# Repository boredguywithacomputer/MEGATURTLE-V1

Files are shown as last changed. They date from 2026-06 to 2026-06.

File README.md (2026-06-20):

  # MEGATURTLE-V1
An ESP32-S3 based custom drone flight controller that is a part of a bigger project. This is not the entire project, but is the only part that needs funding. 

<a href='https://epicturtle.web.app/demoflightcontroller/'>Here's a link to a demo</a><br>
<a href='https://epicturtle.web.app/schemm.pdf'>PDF version of schematic</a>

It features
- 4 connectors for each individual ESC of my quadcopter
  -  One ESC will supply 5v for the flight controller
- A voltage divider setup that enables measurement of the LiPo battery's voltage and capacity
- An ESP32-S3 Wroom-1 microcontroller
- An IMU consisting of Bosch's BMI270 + BMM150, and an BMP388 Barometer
- Sockets to mount an NRF24L01 module

Note:
DRC says the courtyard two header pins overlap with those of the ESP32's antenna, but I ignored it since I won't need wireless connectivity. 

# Schematic


# Board

<br>



# Bill Of Materials
|Component |Total Price ($)|Part # |Link |Qty|JLCPCB Part #|
|---|---|---|---|---|---|
|22uF |0.472 |CL10A226MQ8NRNC |https://jlcpcb.com/partdetail/60514-CL10A226MQ8NRNC/C59461 |20 |C59461 |
|1uF |0.284 |CL05A105KA5NQNC |https://jlcpcb.com/partdetail/53938-CL05A105KA5NQNC/C52923 |20 |C52923 |
|10uF |0.524 |CL10A106KP8NNNC |https://jlcpcb.com/partdetail/20411-CL10A106KP8NNNC/C19702 |20 |C19702 |
|0.1uF |0.0868 |CL05B104KO5NNNC |https://jlcpcb.com/partdetail/1877-CL05B104KO5NNNC/C1525 |28 |C1525 |
|LED |0.144 |KT-0603R |https://jlcpcb.com/partdetail/Hubei_KENTOElec-KT0603R/C2286 |20 |C2286 |
|BMP388 |4.7298 |BMP388 |https://jlcpcb.com/partdetail/BoschSensortec-BMP388/C779278 |2  |C779278 |
|BMI270 |6.501 |BMI270 |https://jlcpcb.com/partdetail/BoschSensortec-BMI270/C2836813 |2  |C2836813 |
|USB_C_Receptacle_USB2.0_14P|0.3686 |TYPE-C-31-M-12 |https://jlcpcb.com/partdetail/Korean_HropartsElec-TYPE_C_31_M12/C165948  |2  |C165948 |
|Conn_01x03_Pin |7.0924 |TSM-103-01-L-SV |https://jlcpcb.com/partdetail/Samtec-TSM_103_01_LSV/C6886650 |14 |C6886650 |
|Conn_01x03_Pin | | | | | |
|NRF24L01 |0.3618 |PM254-2-04-S-8.5 |https://jlcpcb.com/partdetail/HCTL-PM254_2_04_S_85/C3975149 |2  |C3975149 |
|10K |0.024 |0402WGF1002TCE |https://jlcpcb.com/partdetail/26487-0402WGF1002TCE/C25744 |20 |C25744 |
|100K |0.022 |0402WGF1003TCE |https://jlcpcb.com/partdetail/26484-0402WGF1003TCE/C25741 |20 |C25741 |
|5.1K |0.018 |0402WGF5101TCE |https://jlcpcb.com/partdetail/26648-0402WGF5101TCE/C25905 |20 |C25905 |
|33K |0.016 |0402WGF3302TCE |https://jlcpcb.com/partdetail/26522-0402WGF3302TCE/C25779 |20 |C25779 |
|1K |0.022 |0402WGF1001TCE |https://jlcpcb.com/partdetail/12256-0402WGF1001TCE/C11702 |20 |C11702 |
|SW_Push |0.4416 |TS-1088-AR02016 |https://jlcpcb.com/partdetail/XUNPU-TS_1088AR02016/C720477 |8  |C720477 |
|ESP32-S3-WROOM-1 |9.6078 |ESP32-S3-WROOM-1-N8 |https://jlcpcb.com/partdetail/3198296-ESP32_S3_WROOM_1N8/C2913198 |2  |C2913198 |
|AMS1117 |0.3944 |AMS1117-3.3 |https://jlcpcb.com/partdetail/Advanced_MonolithicSystems-AMS1117_33/C6186|2  |C6186 |
|BMM150 |3.1424 |BMM150 |https://jlcpcb.com/partdetail/BoschSensortec-BMM150/C171681 |2  |C171681 |
|PCB Price |7 | | | | |
|Standard PCBA Setup |25.56 |*board must be standard pcba because of some components I'm using| | | |
|Stencil |8.21 | | | | |
|Total |75.0226 | | | | |

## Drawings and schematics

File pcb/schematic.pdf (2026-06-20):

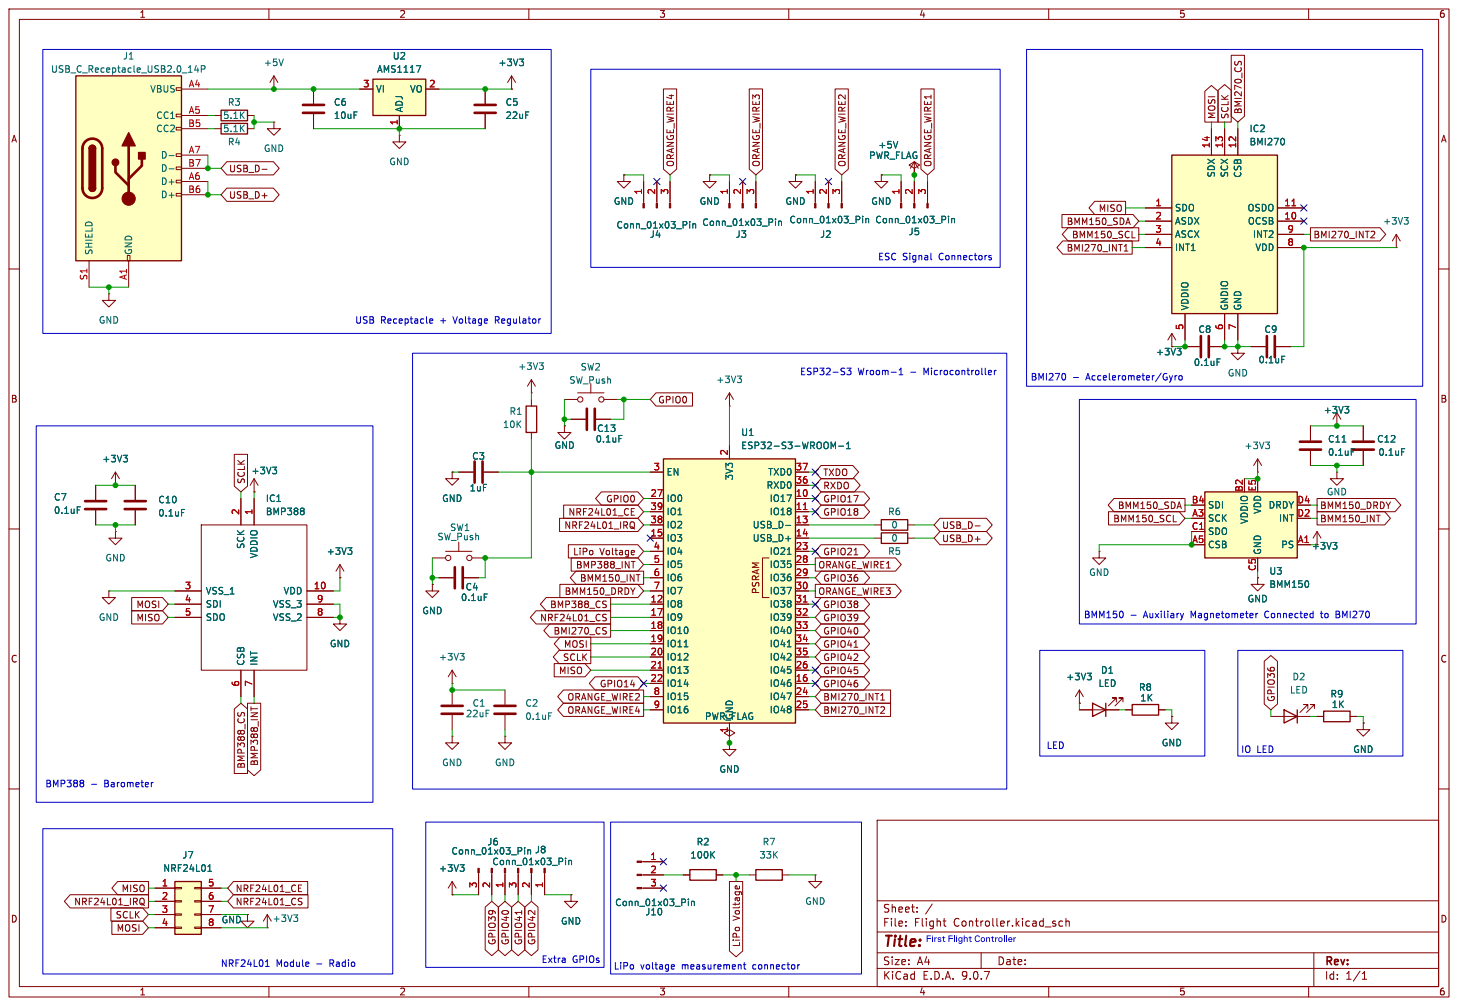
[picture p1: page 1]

Id: 1/1 Title: File: Flight Controller.kicad_sch Sheet: /

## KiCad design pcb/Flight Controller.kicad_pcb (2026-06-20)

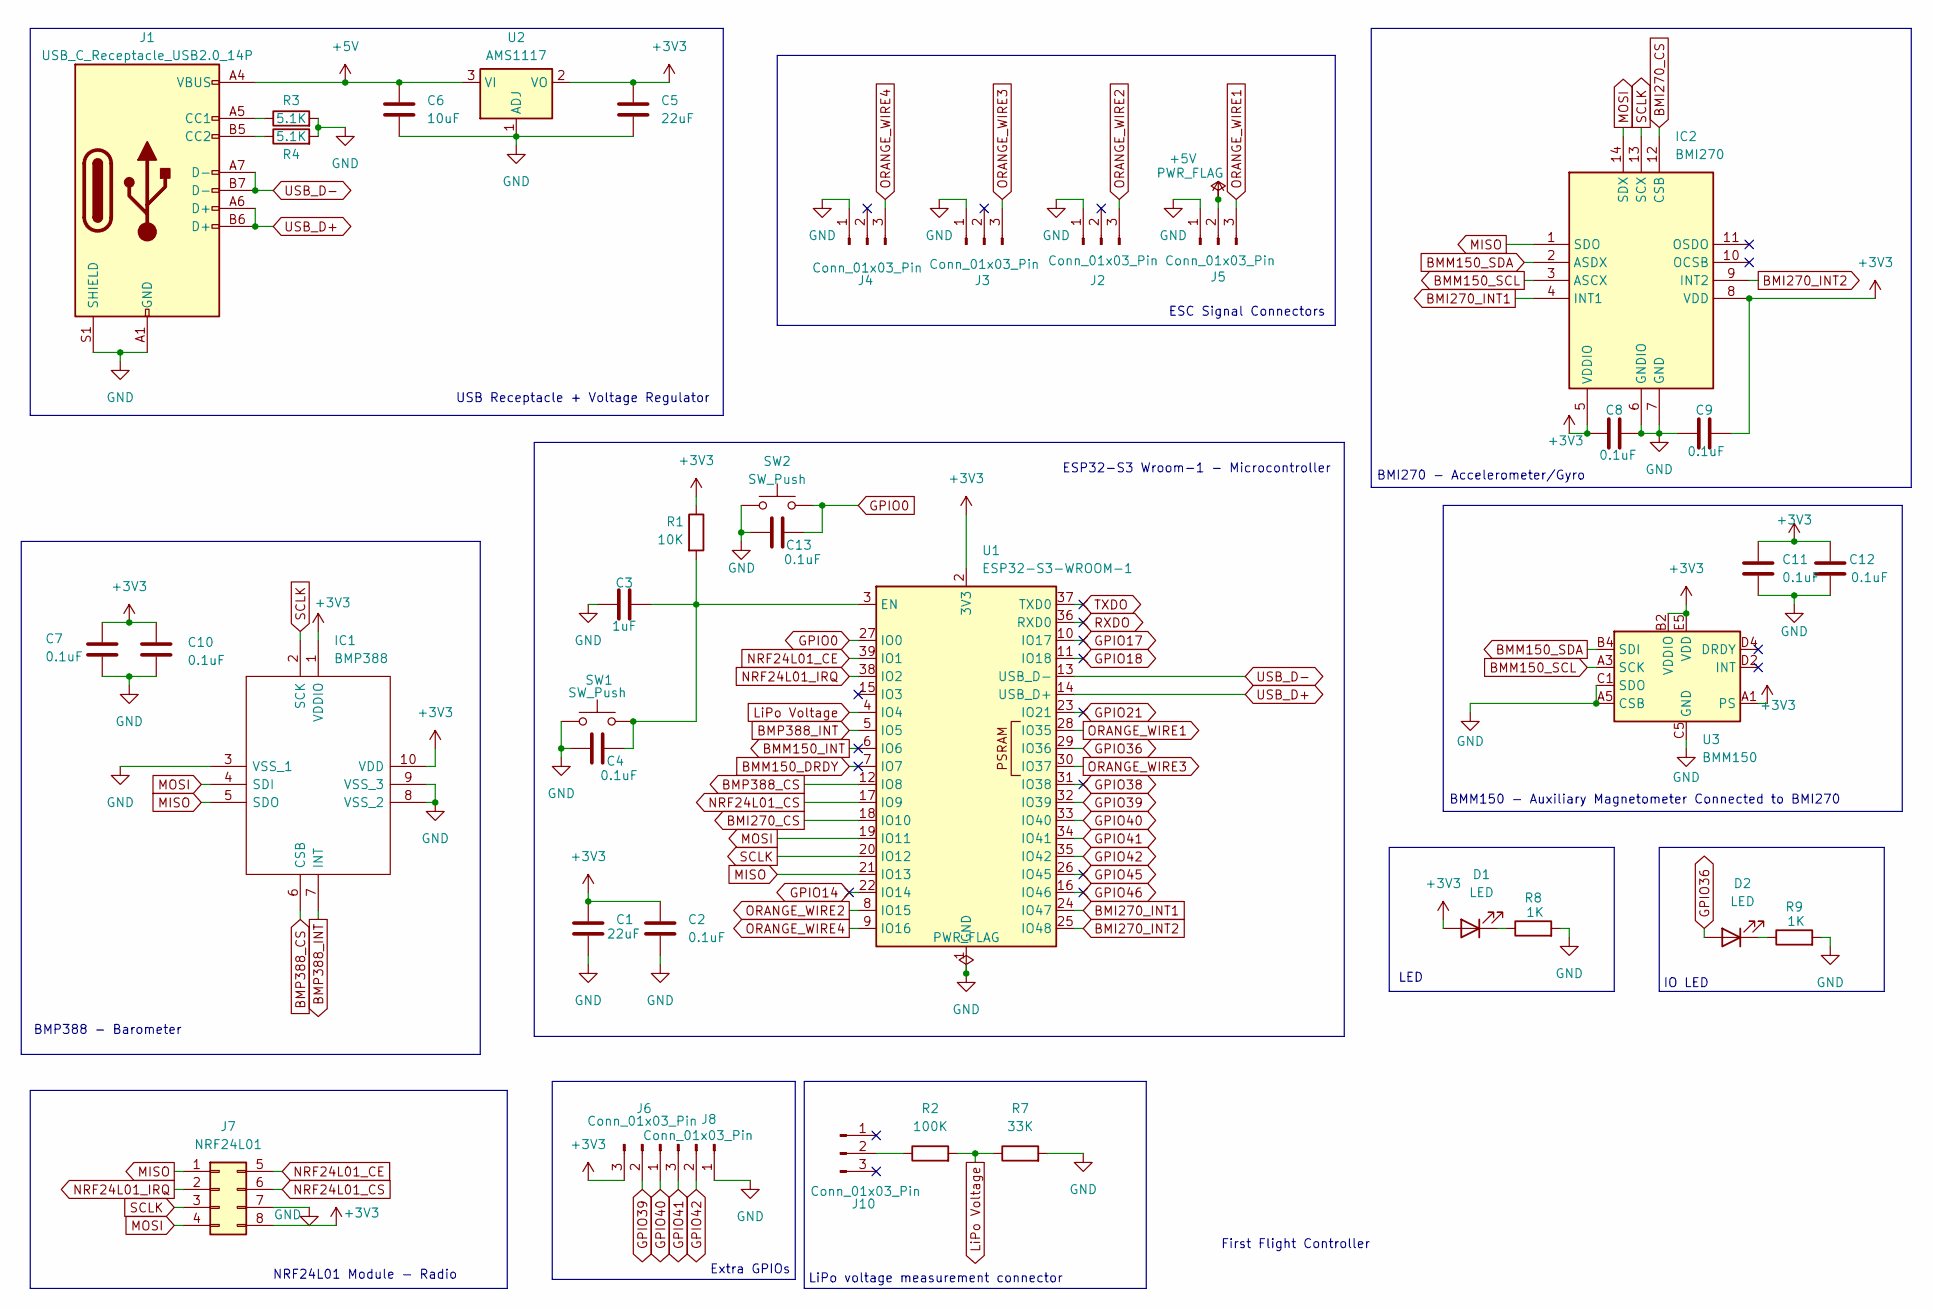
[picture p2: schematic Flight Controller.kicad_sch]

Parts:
C1, C5: 22uF; C_0603_1608Metric
C2, C4, C7, C8, C9, C10, C11, C12, C13: 0.1uF; C_0402_1005Metric
C3: 1uF; C_0402_1005Metric
C6: 10uF; C_0603_1608Metric
D1, D2: LED; LED_0603_1608Metric
IC1: BMP388; Manufacturer_Part_Number BMP388
IC2: BMI270; Manufacturer_Part_Number BMI270; Mouser Part Number 262-BMI270
J1: USB_C_Receptacle_USB2.0_14P; USB_C_Receptacle_HRO_TYPE-C-31-M-12
J2, J3, J4, J5, J6, J8: Conn_01x03_Pin; PinHeader_1x03_P2.54mm_Vertical_SMD_Pin1Left
J7: NRF24L01; PinSocket_2x04_P2.54mm_Vertical_SMD
J10: Conn_01x03_Pin; PinSocket_1x03_P2.54mm_Vertical_SMD_Pin1Left
R1: 10K; R_0402_1005Metric
R2: 100K; R_0402_1005Metric
R3, R4: 5.1K; R_0402_1005Metric
R7: 33K; R_0402_1005Metric
R8, R9: 1K; R_0402_1005Metric
SW1, SW2: SW_Push; SW_Push_SPST_NO_Alps_SKRK
U1: ESP32-S3-WROOM-1
U2: AMS1117; SOT-223-3_TabPin2
U3: BMM150; WLCSP-12_1.56x1.56mm_P0.4mm

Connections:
+3V3: C1.1, C2.1, C5.1, C7.1, C8.1, C9.2, C10.1, C11.1, C12.1, D1.2 (A), IC1.1 (VDDIO), IC1.10 (VDD), IC2.5 (VDDIO), IC2.8 (VDD), J6.3, J7.8, R1.1, U1.2 (3V3), U2.2 (VO), U3.A1 (PS), U3.B2 (VDDIO), U3.E5 (VDD)
+5V: C6.1, J1.A4 (VBUS), J1.A9 (VBUS), J1.B4 (VBUS), J1.B9 (VBUS), J5.2, U2.3 (VI)
BMI270_CS: IC2.12 (CSB), U1.18 (IO10)
BMI270_INT1: IC2.4 (INT1), U1.24 (IO47)
BMI270_INT2: IC2.9 (INT2), U1.25 (IO48)
BMM150_DRDY: U1.7 (IO7)
BMM150_INT: U1.6 (IO6)
BMM150_SCL: IC2.3 (ASCX), U3.A3 (SCK)
BMM150_SDA: IC2.2 (ASDX), U3.B4 (SDI)
BMP388_CS: IC1.6 (CSB), U1.12 (IO8)
BMP388_INT: IC1.7 (INT), U1.5 (IO5)
GND: C1.2, C2.2, C3.1, C4.1, C5.2, C6.2, C7.2, C8.2, C9.1, C10.2, C11.2, C12.2, C13.1, IC1.3 (VSS_1), IC1.8 (VSS_2), IC1.9 (VSS_3), IC2.6 (GNDIO), IC2.7 (GND), J1.A1 (GND), J1.A12 (GND), J1.B1 (GND), J1.B12 (GND), J1.S1 (SHIELD), J2.1, J3.1, J4.1, J5.1, J7.7, J8.1, R3.2, R4.2, R7.2, R8.2, R9.2, SW1.1, SW2.1, U1.1 (GND), U1.40 (GND), U1.41 (GND), U2.1 (ADJ), U3.A5 (CSB), U3.C1 (SDO), U3.C5 (GND), U3.E1 (GND), U3.E3 (GND)
GPIO0: C13.2, SW2.2, U1.27 (IO0)
GPIO14: U1.22 (IO14)
GPIO17: U1.10 (IO17)
GPIO18: U1.11 (IO18)
GPIO21: U1.23 (IO21)
GPIO36: D2.2 (A), U1.29 (IO36)
GPIO38: U1.31 (IO38)
GPIO39: J6.2, U1.32 (IO39)
GPIO40: J6.1, U1.33 (IO40)
GPIO41: J8.3, U1.34 (IO41)
GPIO42: J8.2, U1.35 (IO42)
GPIO45: U1.26 (IO45)
GPIO46: U1.16 (IO46)
LiPo Voltage: R2.2, R7.1, U1.4 (IO4)
MISO: IC1.5 (SDO), IC2.1 (SDO), J7.1, U1.21 (IO13)
MOSI: IC1.4 (SDI), IC2.14 (SDX), J7.4, U1.19 (IO11)
NRF24L01_CE: J7.5, U1.39 (IO1)
NRF24L01_CS: J7.6, U1.17 (IO9)
NRF24L01_IRQ: J7.2, U1.38 (IO2)
unnamed: D1.1 (K), R8.1
unnamed: D2.1 (K), R9.1
unnamed: J1.A5 (CC1), R3.1
unnamed: J1.B5 (CC2), R4.1
unnamed: J10.2, R2.1
unnamed: C3.2, C4.2, R1.2, SW1.2, U1.3 (EN)
ORANGE_WIRE1: J5.3, U1.28 (IO35)
ORANGE_WIRE2: J2.3, U1.8 (IO15)
ORANGE_WIRE3: J3.3, U1.30 (IO37)
ORANGE_WIRE4: J4.3, U1.9 (IO16)
RXDO: U1.36 (RXD0)
SCLK: IC1.2 (SCK), IC2.13 (SCX), J7.3, U1.20 (IO12)
TXDO: U1.37 (TXD0)
USB_D+: J1.A6 (D+), J1.B6 (D+), U1.14 (USB_D+)
USB_D-: J1.A7 (D-), J1.B7 (D-), U1.13 (USB_D-)

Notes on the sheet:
USB Receptacle + Voltage Regulator
BMM150 - Auxiliary Magnetometer Connected to BMI270
LED
LiPo voltage measurement connector
NRF24L01 Module - Radio
BMP388 - Barometer
Extra GPIOs
First Flight Controller
BMI270 - Accelerometer/Gyro
ESC Signal Connectors
ESP32-S3 Wroom-1 - Microcontroller
IO LED

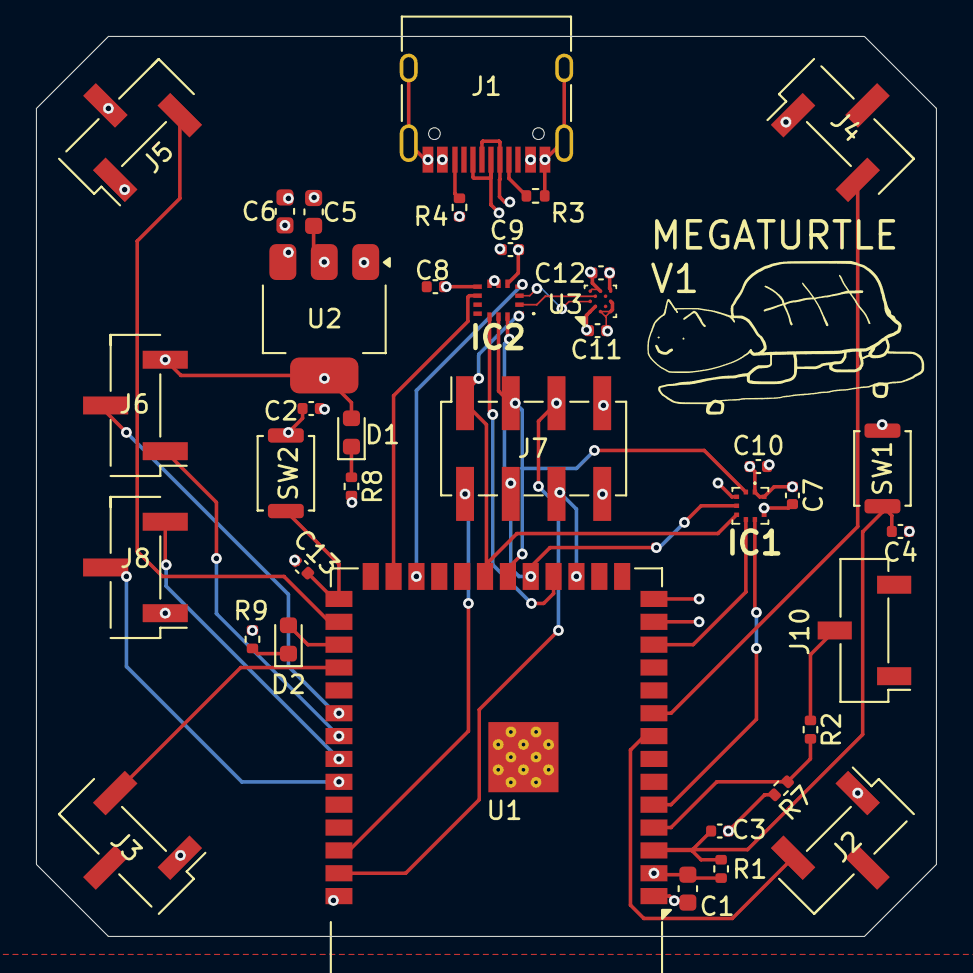
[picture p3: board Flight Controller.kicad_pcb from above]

Board: 4 copper layers, 50.0 x 50.0 mm, 38 parts (0 on the bottom side), 35 nets.

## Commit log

2026-06-20 added stuff
    yea
    [Flight Controller.kicad_pcb, Flight Controller.kicad_sch, FlightControllerBOM.csv]
2026-06-20 Add Bill of Materials to README
    Added a Bill of Materials section with component details and pricing.
